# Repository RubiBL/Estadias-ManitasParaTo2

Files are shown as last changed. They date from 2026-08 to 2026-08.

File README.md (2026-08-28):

<div align="center">

  # Guía de Impresión, Edición y Ensamblado de Prótesis Electromecánica

  **Manual técnico interactivo e instructivo de construcción para la prótesis de mano de *ManitasParaTodo2***

  
  
  

  <br />

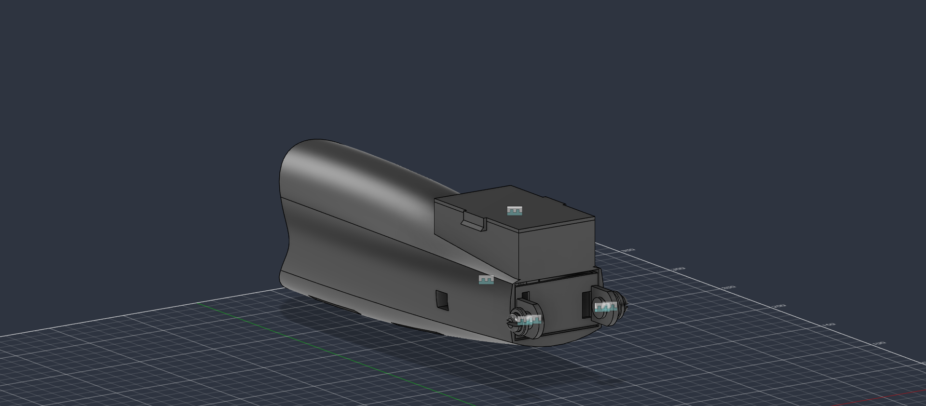
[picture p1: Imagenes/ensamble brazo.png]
Vista previa de ensamblado de prótesis
  

</div>

---

## 📋 Tabla de Contenidos

- [📌 Sobre el Proyecto](#-sobre-el-proyecto)
- [🧩 Estructura de Archivos CAD / 3D](#-estructura-de-archivos-cad--3d)
- [🖨️ Parámetros Recomendados de Impresión 3D](#️-parámetros-recomendados-de-impresión-3d)
- [🛠️ Lista de Materiales y Componentes (BOM)](#️-lista-de-materiales-y-componentes-bom)
- [✏️ Guía de Edición y Modificación CAD](#️-guía-de-edición-y-modificación-cad)
- [⚙️ Paso a Paso: Guía de Ensamblado](#️-paso-a-paso-guía-de-ensamblado)
  - [1. Preparación de Piezas 3D](#1-preparación-de-piezas-3d)
  - [2. Mecanismo de Tensión y Hilos](#2-mecanismo-de-tensión-y-hilos)
  - [3. Ensamble de Carcasa y Electrónica](#3-ensamble-de-carcasa-y-electrónica)
- [🤝 Contribución y Créditos](#-contribución-y-créditos)

---

## 📌 Sobre el Proyecto

Este repositorio contiene el diseño, archivos de modelado 3D y documentación técnica para la fabricación de una **prótesis electromecánica de mano**. El proyecto está concebido para ser modificado, impreso en 3D y ensamblado con componentes estándar de bajo costo.

> 💡 **Nota:** Este manual está estructurado como una guía paso a paso para makers, ingenieros y protesistas que busquen replicar o adaptar el diseño.

---

## 🧩 Estructura de Archivos CAD / 3D

Los modelos 3D de la versión **Electromecanica Final** se encuentran en la carpeta [`Modelos/Electromecanica Final`](./Modelos/Electromecanica%20Final/). Incluye archivos editables de Fusion 360 (`.f3d`), archivos listos para laminar (`.stl`) y archivos completos de ensamble o impresión (`.f3z` y `.3mf`).

### Archivos editables y de ensamble

| Archivo | Tipo | Descripción / Función |
| :--- | :--- | :--- |
| [`Brazo.f3d`](./Modelos/Electromecanica%20Final/Brazo.f3d) | Fusion 360 | Estructura principal de la prótesis. |
| [`Caja de Componentes.f3d`](./Modelos/Electromecanica%20Final/Caja%20de%20Componentes.f3d) | Fusion 360 | Caja para alojar componentes. |
| [`carrete servomotor.f3d`](./Modelos/Electromecanica%20Final/carrete%20servomotor.f3d) | Fusion 360 | Carrete para el mecanismo de tracción del servomotor. |
| [`Clip.f3d`](./Modelos/Electromecanica%20Final/Clip.f3d) | Fusion 360 | Clip de sujeción. |
| [`seguro clip.f3d`](./Modelos/Electromecanica%20Final/seguro%20clip.f3d) | Fusion 360 | Seguro del clip. |
| [`Tapa Pilas.f3d`](./Modelos/Electromecanica%20Final/Tapa%20Pilas.f3d) | Fusion 360 | Tapa del compartimento de pilas. |
| [`ensamble brazo.f3z`](./Modelos/Electromecanica%20Final/ensamble%20brazo.f3z) | Ensamble Fusion 360 | Ensamble del brazo. |
| [`Electromecanica.3mf`](./Modelos/Electromecanica%20Final/Electromecanica.3mf) | Proyecto 3MF | Archivo de proyecto para impresión 3D. |

### Archivos STL para impresión

| Archivo | Pieza |
| :--- | :--- |
| [`Brazo.stl`](./Modelos/Electromecanica%20Final/Brazo.stl) | Brazo |
| [`Caja de Componentes.stl`](./Modelos/Electromecanica%20Final/Caja%20de%20Componentes.stl) | Caja de componentes |
| [`carrete servomotor.stl`](./Modelos/Electromecanica%20Final/carrete%20servomotor.stl) | Carrete del servomotor |
| [`Clip.stl`](./Modelos/Electromecanica%20Final/Clip.stl) | Clip |
| [`seguro clip.stl`](./Modelos/Electromecanica%20Final/seguro%20clip.stl) | Seguro del clip |
| [`Tapa Pilas.stl`](./Modelos/Electromecanica%20Final/Tapa%20Pilas.stl) | Tapa de pilas |
| [`LH_Finger_Plate.stl`](./Modelos/Electromecanica%20Final/LH_Finger_Plate.stl) | Placa de dedos |
| [`Ligamentos de mano.stl`](./Modelos/Electromecanica%20Final/Ligamentos%20de%20mano.stl) | Ligamentos de mano |
| [`Mano V4.stl`](./Modelos/Electromecanica%20Final/Mano%20V4.stl) | Mano, versión 4 |
| [`Tapa Mano.stl`](./Modelos/Electromecanica%20Final/Tapa%20Mano.stl) | Tapa de mano |

---

## 🖨️ Parámetros Recomendados de Impresión 3D

Para asegurar la resistencia mecánica de las articulaciones y carcasas, se sugieren los siguientes parámetros en tu software laminador (Eleego Slicer):

| Parámetro | Valor / Configuración Recomendada |
| :--- | :--- |
| **Material** |  PLA  / TPU (Ligamentos) |
| **Altura de Capa** | 0.20 mm  |
| **Relleno (Infill)** | 25% (Patrón Giroide) 10% Prototipos |
| **Soportes** | Árbol (Organic/Tree) Pendiente Maxima 10|
| **Temperatura Boquilla** | 210 °C (PLA) |
| **Temperatura Cama** |  60 °C (PLA) |

## 🛠️ Lista de Materiales y Componentes (BOM)

### Impresión 3D y Estructura
- Piezas impresas en 3D (`.stl`)
- Hilo multifilamento / Hilo de pescar de alto libraje (Braided Line 50lb+)
- Asegurador de Hilos

### Electrónica y Mecánica
- 1 Servomotor (ds3240mg)
- 1x Placa de control 
- 2x Batería Li-Ion (18650 12000mAh)
- Tornillería M2.5 y M3
- Hilo de Pesca 
- Manga Conectora (Hilos) 

---

## ✏️ Guía de Edición y Modificación CAD

Si necesitas adaptar las medidas a un usuario específico o cambiar la cavidad del muñón/electrónica:

1. Abrir el archivo `.f3d` correspondiente en **Autodesk Fusion 360**.
2. **Ajuste de Escala:** Modifica la escala general del ensamble de la palma y dedos en función del tamaño antropométrico deseado.
3. **Modificación de Carcasa:** En el árbol de operaciones, localiza los bocetos (sketches) del *Enclosure* para ajustar el espacio de baterías o controladores.
4. **Exportar a STL:**
   - Ve a `Archivo` > `Exportar` > Formato `.stl` (o clic derecho en el componente principal > `Guardar como malla`).

---

## ⚙️ Paso a Paso: Guía de Ensamblado

### 1. Preparación de Piezas 3D
- [ ] Retirar soportes cuidadosamente de los agujeros de articulación.
- [ ] Verificar y Remover reciduos de filamento

---

### 2. Mecanismo de Tensión y Hilos
-[ ] Armar los dedos y colocarlos en la mano.
<div align="center">
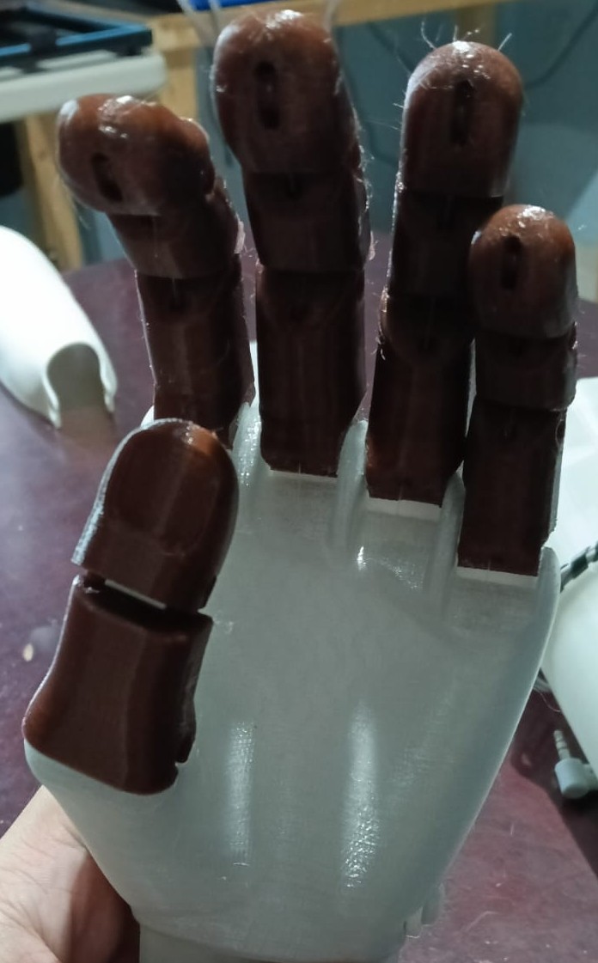
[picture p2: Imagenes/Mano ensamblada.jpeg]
Mano ensamblada
  
</div>
-[ ] Pasar los hilos por los orificios de la mano y dedos.

-[ ] La punta de los dedos cuanta con dos canales el inferios y superior, se debe pasar primero por el canal inferior para depues sacarlo por el interior.
<div align="center">
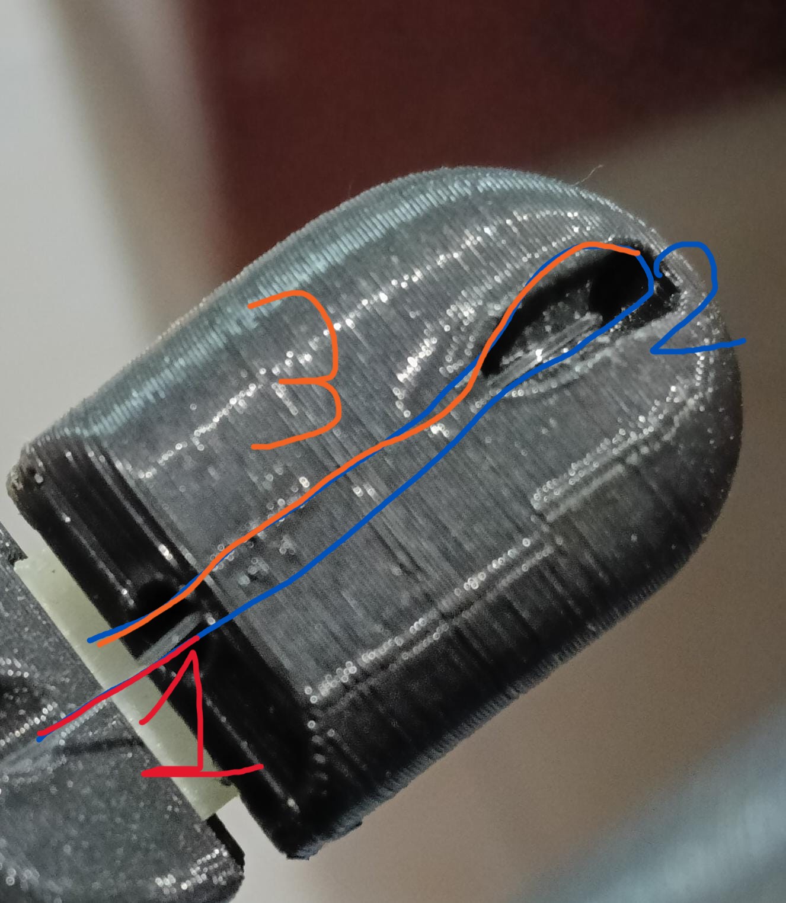
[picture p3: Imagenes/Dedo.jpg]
  
</div>
-[ ] Asegurarse que el nudo quede dentro de los canales del Hilo.
 <div align="center">
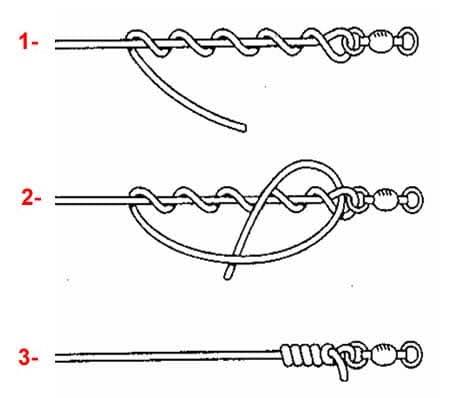
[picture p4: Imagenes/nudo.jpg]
ejemplo de nudo a realizar
  
</div>
 ⚠️ **Advertencia:** Verificar los hilos esten bien amarrados y los dedos se muevan correctamente al tirar de los hilos.

---

### 3. Ensamble de Carcasa y Electrónica
-[ ] Unir la Mano con la Caja de Componentes utilizando los clips y seguros de clips
 <div align="center">
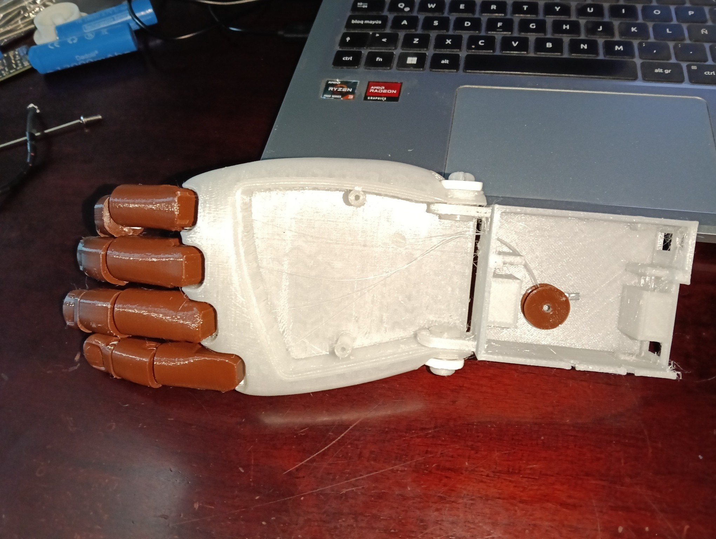
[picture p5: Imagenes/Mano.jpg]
  
</div>
-[ ] Pasar los hilos por el orificio de la Caja de Componentes.
 <div align="center">
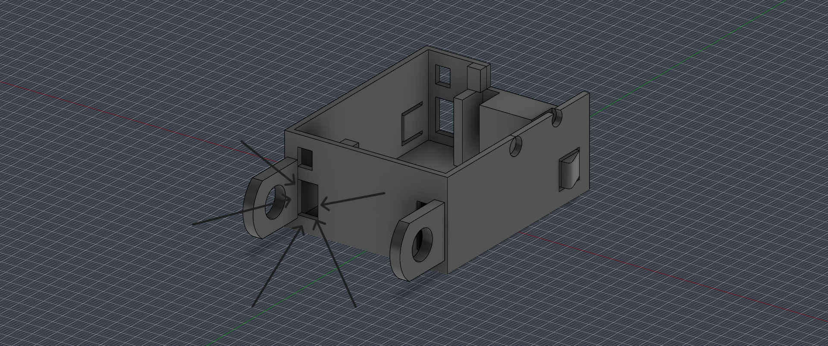
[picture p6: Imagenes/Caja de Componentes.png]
  
</div>
-[ ] Pasar los hilos por el orificio del carrete del servomotor pasando de izquierda a derecha , y asegurandose de moner la manga conectora del lado derecho del carrete.
*Nota: la orientacion del carrete se define por el agujero dentado con el cual se une al servomotor, siendo esta la parte de abajo
 <div align="center">
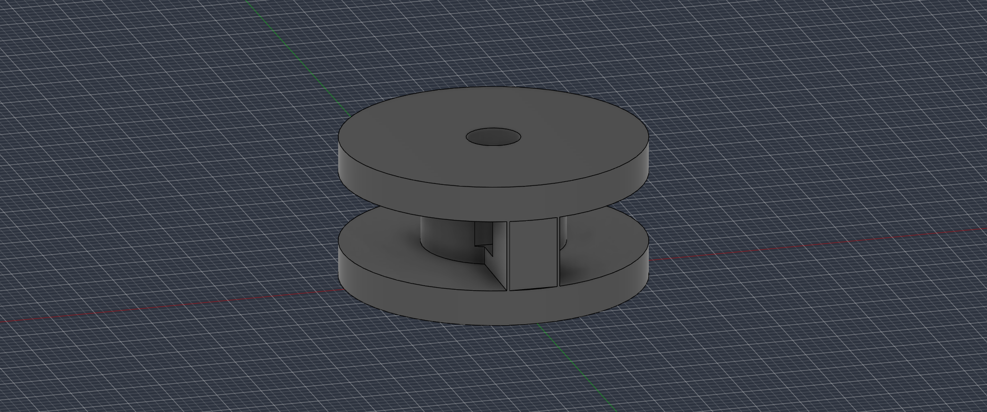
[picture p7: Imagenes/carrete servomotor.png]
  
</div>
-[ ] Al tener listo el carrete se debe de unir al servomotor y asegurarse con un tornillo M3 de 6 mm de longitud.
*Nota: el Servomotor gira hacia la derecha para cerrar la mano y ala izquierda para abrirla.
-[ ] Colocar el servomotor en la caja de componentes de la siguiente manera (el cable debe de pasar por el orificio de la caja):
 <div align="center">
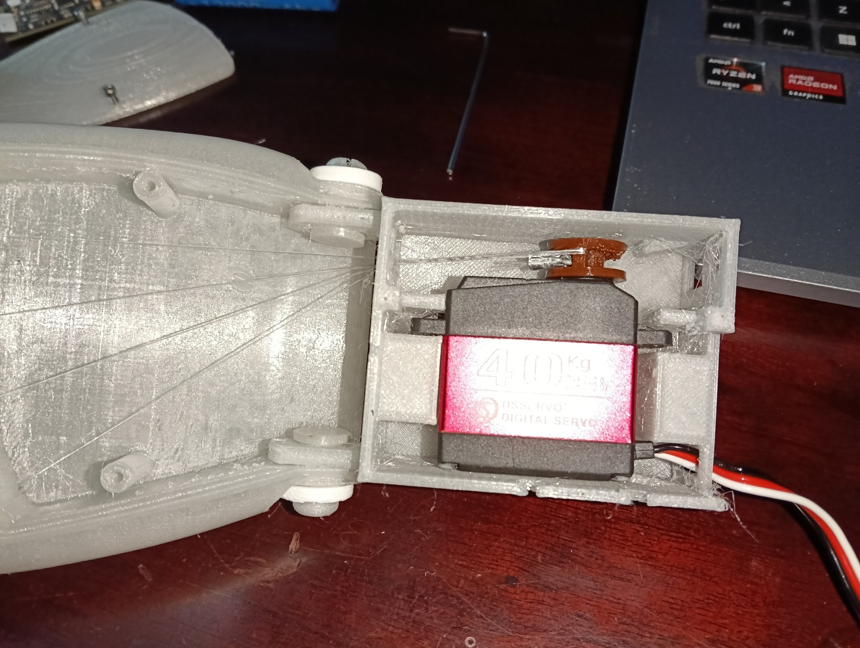
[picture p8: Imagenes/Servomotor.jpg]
  
</div>
-[ ] Atornillar la tapa de la Mano con Tornillos M2.5 de 6mm de longitud(PLanos) para cubrir los hilos.
 <div align="center">
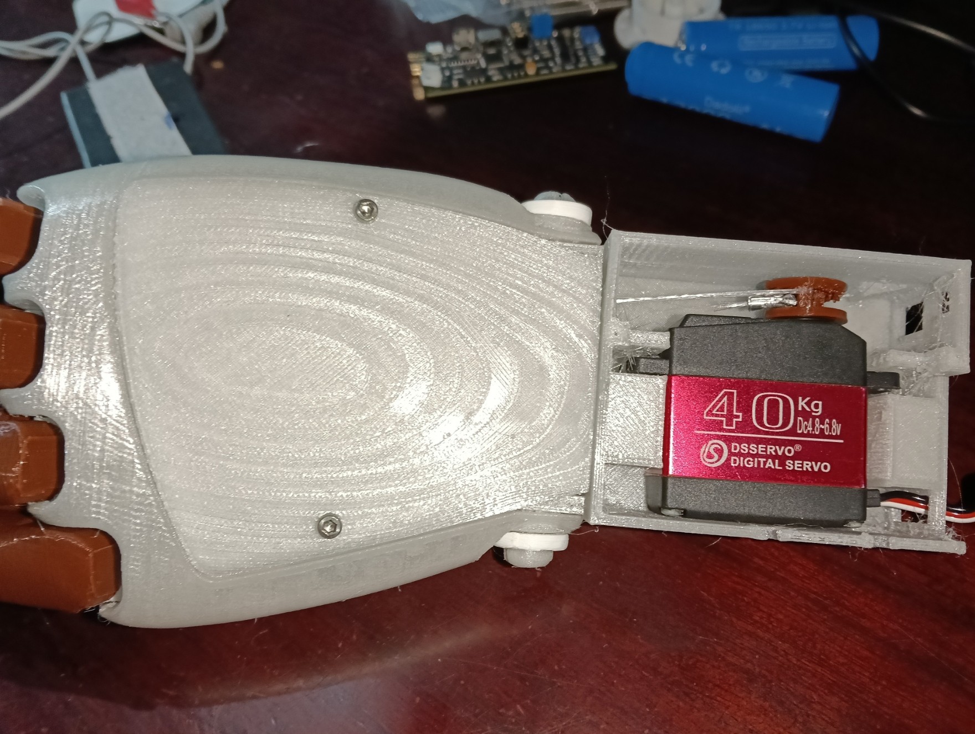
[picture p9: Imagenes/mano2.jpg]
  
</div>
-[ ] Situar la tarjeta de control sobre el servomotor y conectar el servo como indica la tarjeta en la parte inferior.
<div align="center">
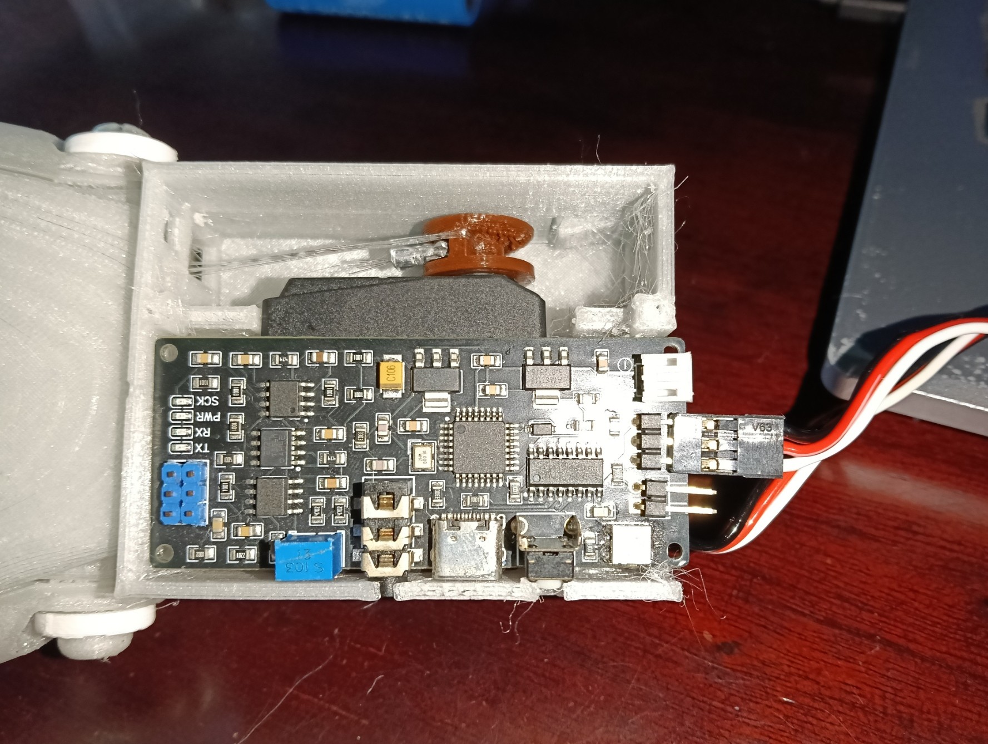
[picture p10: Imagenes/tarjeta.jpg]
  
</div>
-[ ] Para colocar el porta pilas en el brazo se debe de introducir el conector en el agujero dentro del compartimiento del portapilas, para asi tener el conector en el espacio donde ira la caja de componentes.
<div align="center">
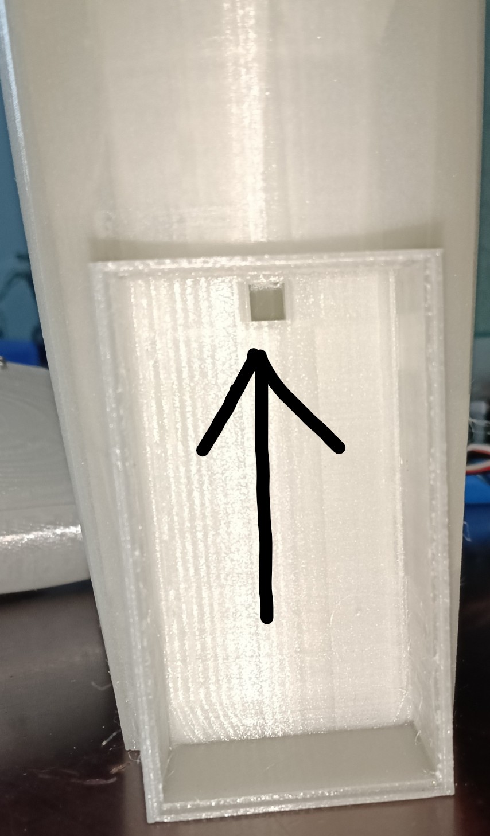
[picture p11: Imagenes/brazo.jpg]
  
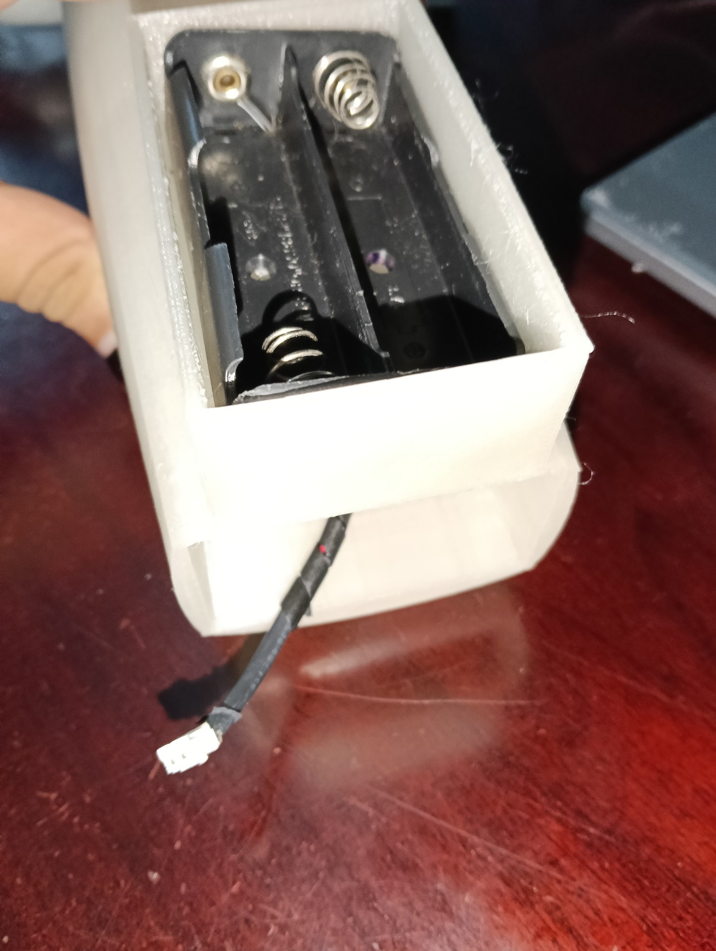
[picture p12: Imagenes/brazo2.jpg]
  
</div>
-[ ] Conectar el portapilas SIN BATERIAS, a la tarjeta de control e introducir la caja de componentes en el brazo teniendo cuidado con los cables, cuando se escuche un click la caja de componentes estara en posición.
<div align="center">
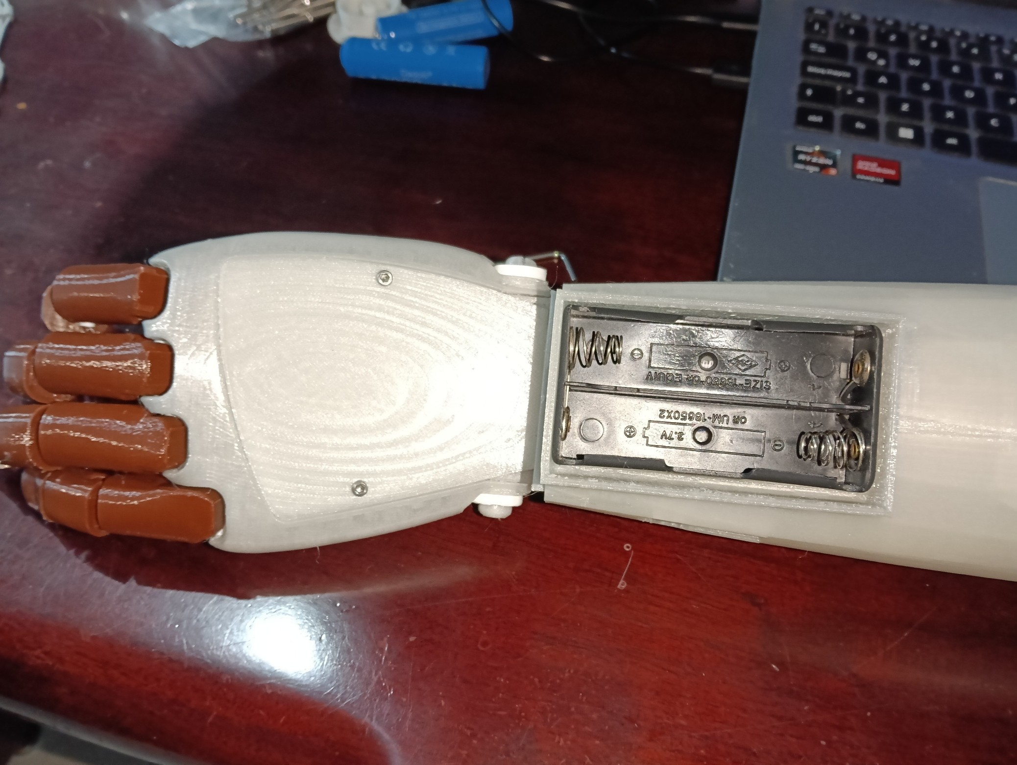
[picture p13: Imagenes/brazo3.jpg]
  
</div>
-[ ] Conectar los sensores mielectricos a la tarjeta y colocar en el brazo como se muestra en la imagen:
<div align="center">
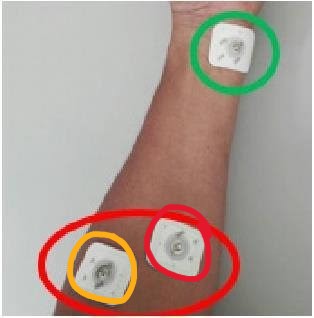
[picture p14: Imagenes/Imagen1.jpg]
  
</div>
-[ ] Insertar Pilas y Probar 

<div align="center">

### ¡Has completado la construcción de la Mano Electromecánica!   
🎉🎉🎉

¡El ensamblado, ajuste de tensores y montaje electrónico están listos para ponerse a prueba!



</div>

## 🤝 Contribución y Créditos

Este repositorio forma parte del proyecto de estadías e investigación para el desarrollo de prótesis electromecánicas de mano.

### 👤 Autor y Desarrollo
* **Desarrollador Principal:** [Ruben Barrios Luna](https://github.com/RubiBL) - *Modelado 3D, prototipado de carcasas, integración electromecánica y sintonización de mecanismos de tensión.*

### 🏛️ Organización y Agradecimientos
* **ManitasParaTodo2:** Por el apoyo, espacio y recursos proporcionados para llevar a cabo el diseño, pruebas e impresión de los prototipos funcionales.

---

<div align="center">
  <sub>¿Encontraste algún problema en la impresión o ensamblado? Abre un <a href="https://github.com/RubiBL/Estadias-ManitasParaTo2/issues">Issue</a> para reportarlo.</sub>
</div>

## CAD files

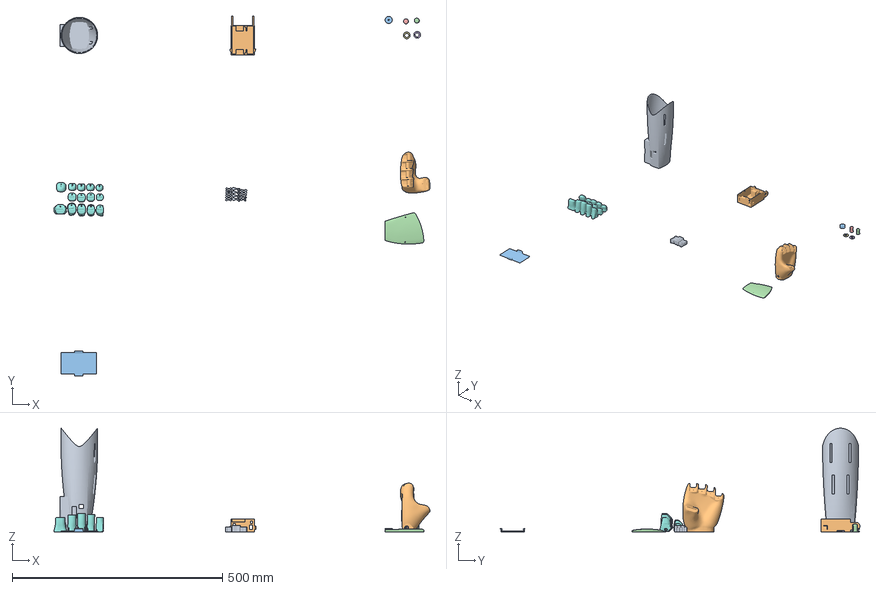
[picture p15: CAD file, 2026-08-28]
Modelos/Electromecanica Final/Electromecanica.3mf
894.4 x 855.9 x 246.5 mm
Brazo.stl
Caja de Componentes.stl
carrete servomotor.stl
Clip.stl x 2
seguro clip.stl x 2
LH_Finger_Plate.stl
Ligamentos de mano.stl
Mano V4.stl
Tapa Pilas.stl
Tapa.stl

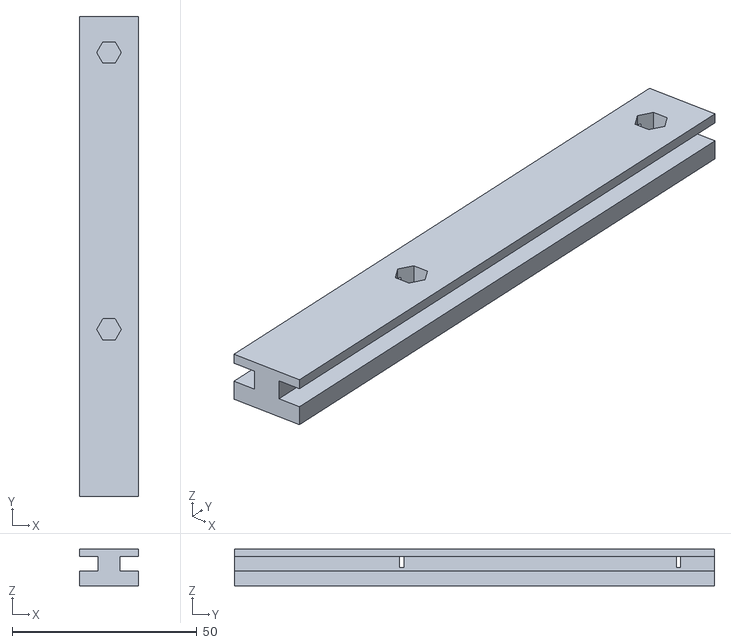
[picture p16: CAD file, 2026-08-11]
Modelos/Electromecanica MK 2/Riel caja.stl
16.0 x 130.0 x 10.0

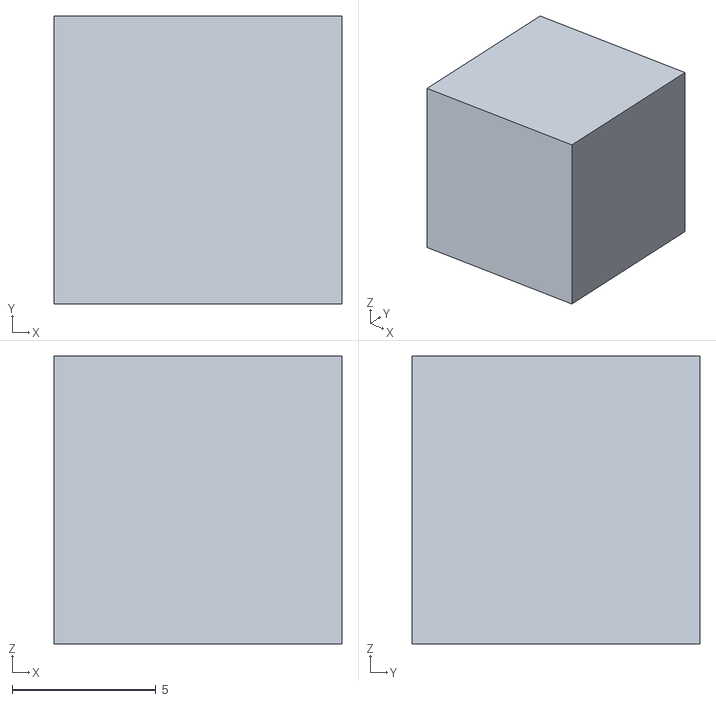
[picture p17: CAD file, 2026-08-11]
Modelos/Pruebas/Cubo.stl
10.0 x 10.0 x 10.0

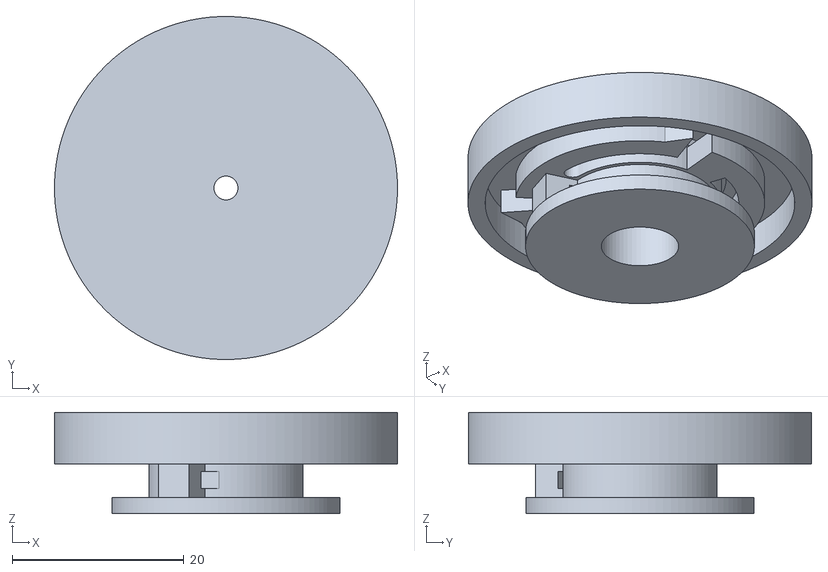
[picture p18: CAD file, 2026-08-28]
Modelos/Sitema BOA/Boa tapa.stl
40.0 x 40.0 x 11.8

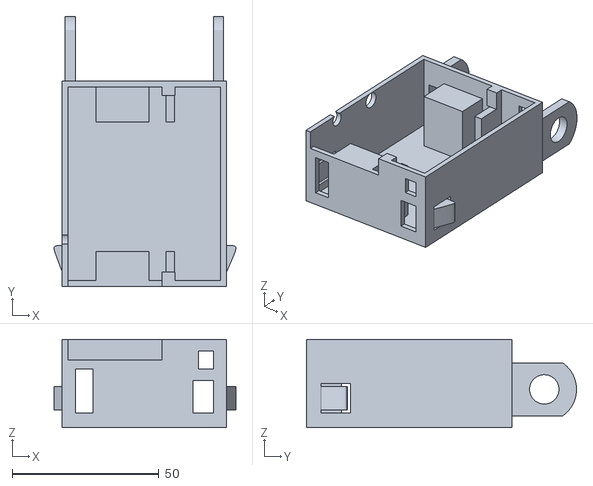
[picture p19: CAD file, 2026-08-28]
Modelos/Electromecanica Final/Caja de Componentes.stl
62.0 x 92.0 x 30.0

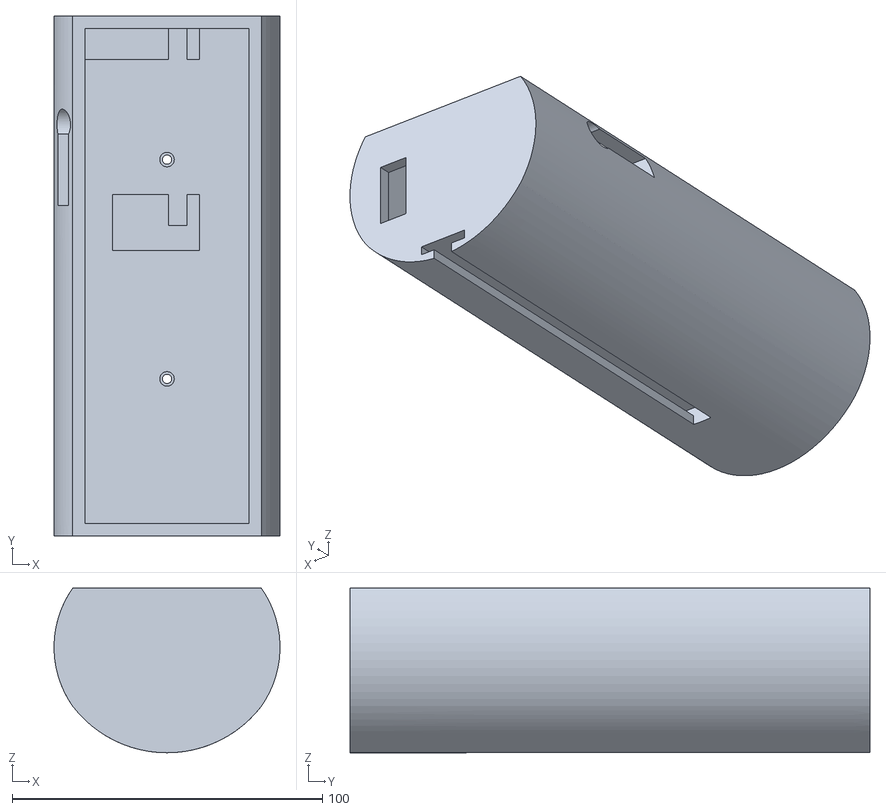
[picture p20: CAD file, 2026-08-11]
Modelos/Electromecanica MK 2/Caja Componentes.stl
72.8 x 167.5 x 53.0

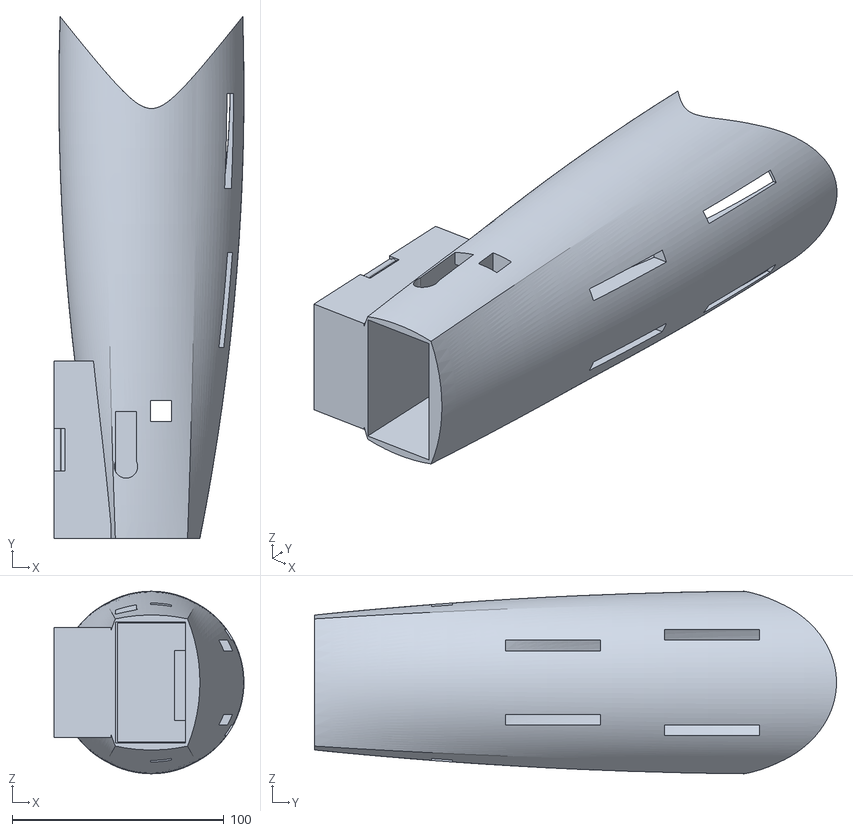
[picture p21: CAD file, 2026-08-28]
Modelos/Electromecanica Final/Brazo.stl
89.7 x 246.5 x 86.2

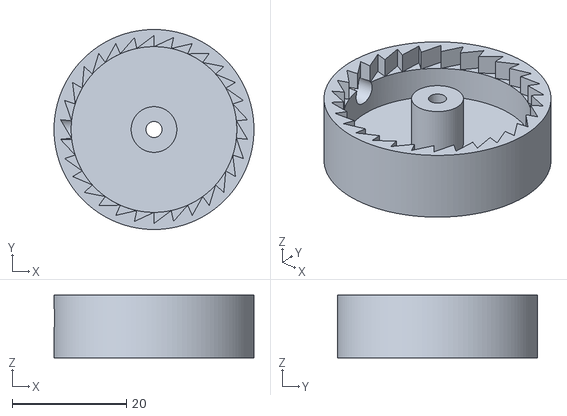
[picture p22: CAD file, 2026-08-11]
Modelos/Sitema BOA/Boa.stl
35.0 x 35.0 x 11.0

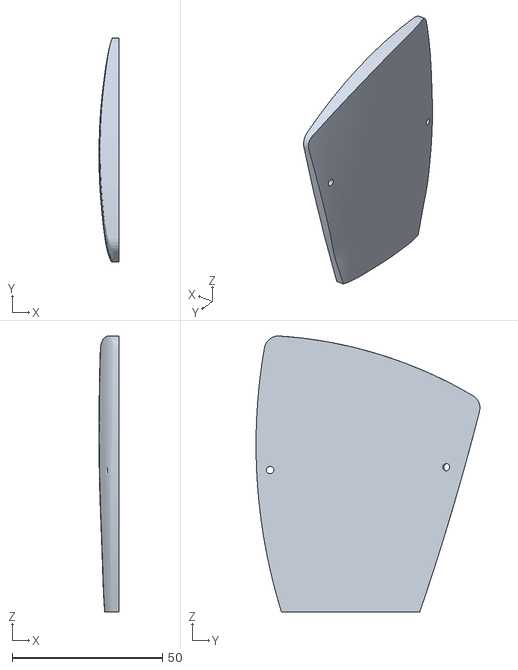
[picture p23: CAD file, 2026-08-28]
Modelos/Electromecanica Final/Tapa Pilas.stl
6.66 x 74.6 x 92.0

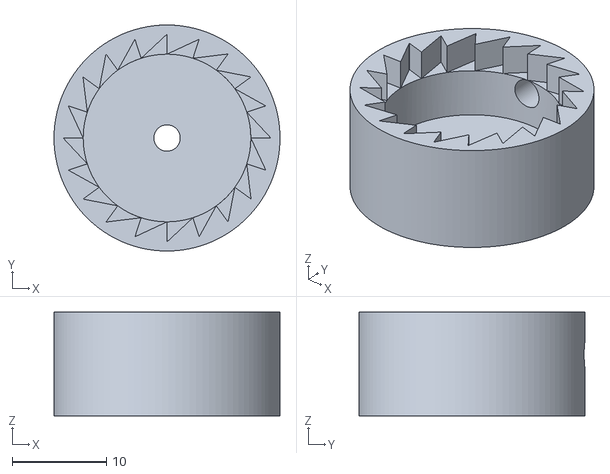
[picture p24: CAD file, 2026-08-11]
Modelos/Sitema BOA/Boa base V2.stl
24.0 x 24.0 x 11.0

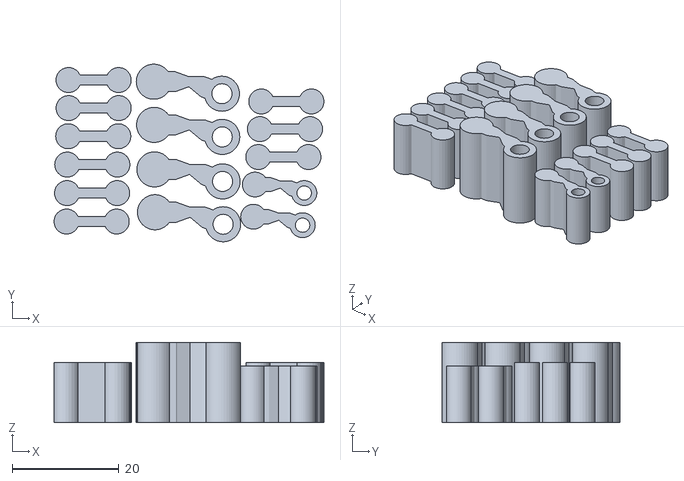
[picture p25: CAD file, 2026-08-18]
Modelos/Electromecanica Final/Ligamentos de mano.stl
50.6 x 33.3 x 15.0

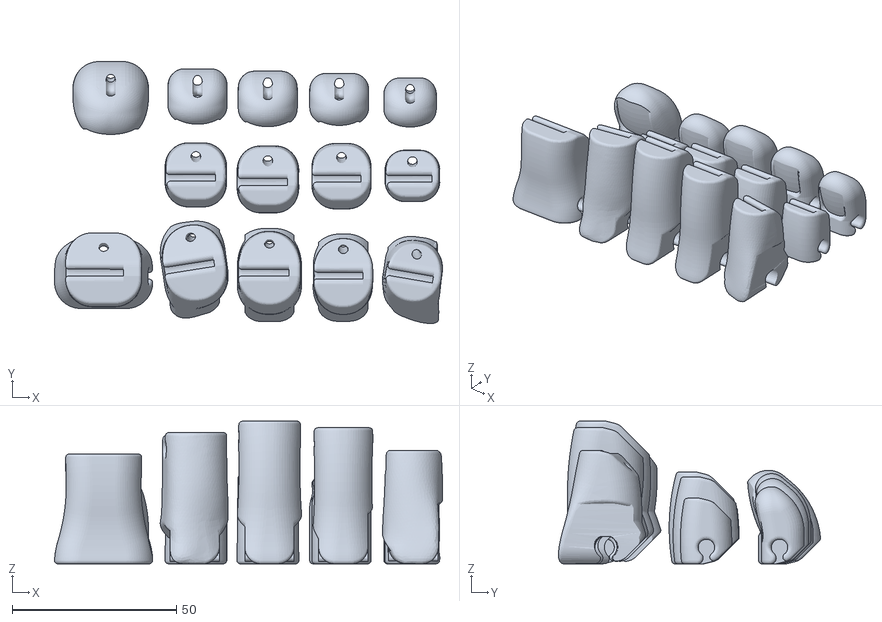
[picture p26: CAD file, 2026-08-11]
Modelos/Electromecanica Final/LH_Finger_Plate.stl
118.3 x 79.9 x 43.5

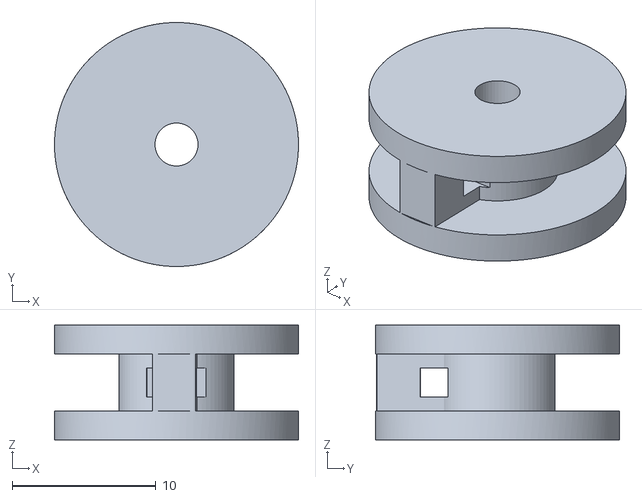
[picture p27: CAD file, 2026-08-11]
Modelos/Electromecanica Final/carrete servomotor.stl
17.0 x 17.0 x 8.00

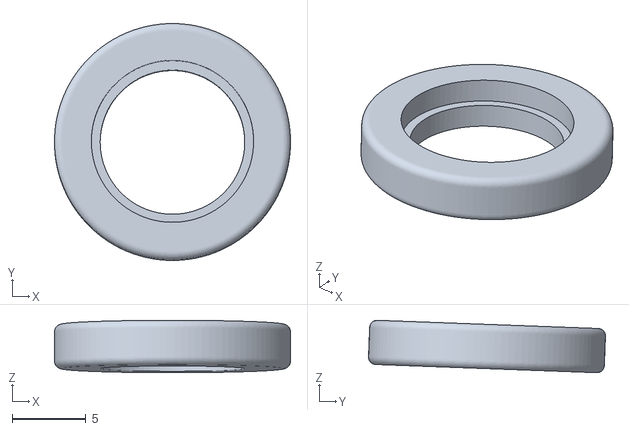
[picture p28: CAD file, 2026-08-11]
Modelos/Electromecanica Final/seguro clip.stl
16.0 x 16.1 x 3.55

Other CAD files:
Modelos/Electromecanica Final/Tapa Mano.stl
Modelos/Electromecanica Final/Clip.stl
Modelos/Sitema BOA/BOA tapa V2.stl
Modelos/Electromecanica Final/Brazo.f3d
Modelos/Electromecanica Final/Caja de Componentes.f3d
Modelos/Electromecanica Final/Clip.f3d
Modelos/Electromecanica Final/Tapa Pilas.f3d
Modelos/Electromecanica Final/carrete servomotor.f3d
Modelos/Electromecanica Final/ensamble brazo.f3z
Modelos/Electromecanica Final/seguro clip.f3d

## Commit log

2026-08-11 Subiendo mis archivos
    [BOA tapa V2.stl, Boa base V2.stl, Boa tapa.stl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]
2026-08-17 Actualizacion del brazo y caja de componentes
    [Brazo mk 1.stl, Clip.3mf, FunMove_LH_Cover_2.stl]
2026-08-18 Adicion de ligamentos adecuados para la mano y modificacion de la mano para atornillar la tapa que cubre los hilos
    [Clip.3mf, FunMove_Finger_Joint.stl, FunMove_Gun_KKB.stl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]
2026-08-28 Edicion de archivos final para el ensamblaje de mano electromecanica
    [Brazo mk 1.stl, Brazo.f3d, Brazo.stl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]
2026-08-28 Cambios de Archivos
    [Clip.3mf, Electromecanica.3mf]
2026-08-28 Instructivo de armado de mano
2026-08-28 actualizacion de imagen

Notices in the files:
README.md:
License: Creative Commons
